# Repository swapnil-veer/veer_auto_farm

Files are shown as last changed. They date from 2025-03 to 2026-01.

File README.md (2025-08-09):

# veer_auto_farm
# Raspberry Pi-Based Auto Farm System

## Overview

This project is a **GSM/GPRS-controlled auto farm system** built using a **Raspberry Pi Zero 2 W**. The system automates motor control and monitors bypass mode, dry-run conditions, and phase availability using relays and sensors. It also includes an LCD display for real-time status updates.

## Hardware Components

- **Raspberry Pi Zero 2 W** – Main microcontroller
- **SIM800L** – GSM/GPRS module for remote control
- **ZMCT103C + ADS1115** – AC current sensor for dry-run detection
- **DPST Switch** – For detecting bypass mode
- **SRD-05VDC-SL-C Relays (2x)** – For motor on/off control and dry-run protection
- **Phase Monitoring Module** – Detects phase loss and faults
- **LCD (I2C)** – Displays system status
- **Power Setup**:
  - AC-DC Adapter (12V, 3A)
  - Li-Ion Batteries (4x DMEGC INR18650-26E)
  - BMS (2S 20A)
  - DC-DC Step Down (XL4015 - 5V, 4.2V, 12V)

## Wiring Diagram

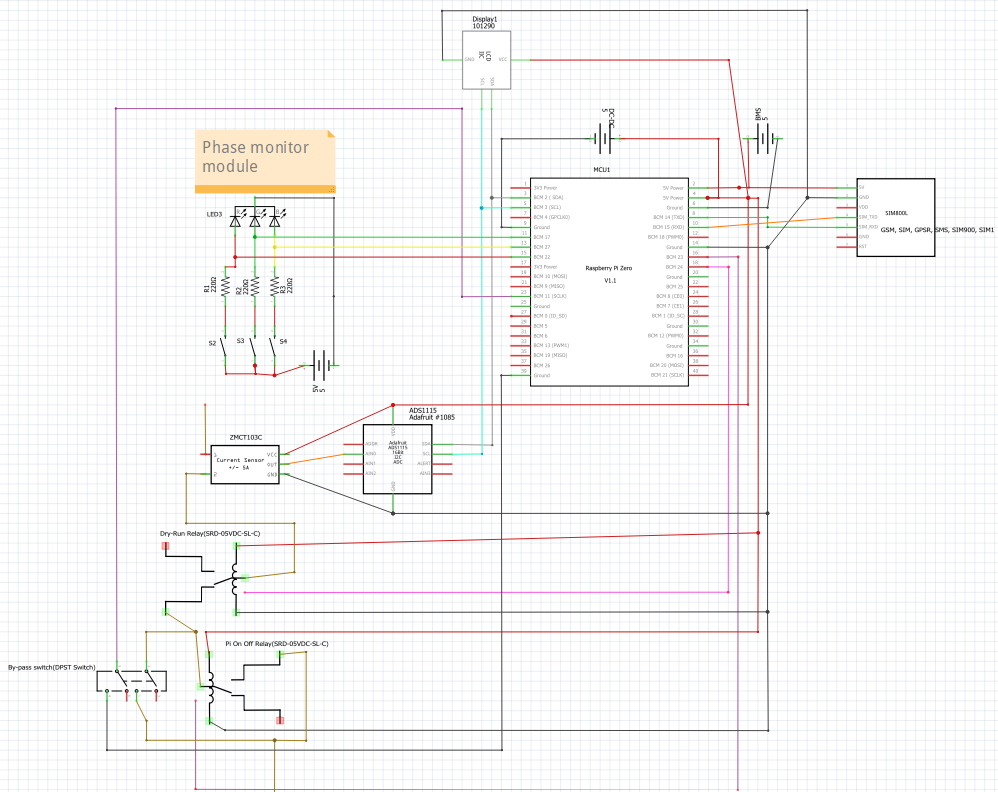
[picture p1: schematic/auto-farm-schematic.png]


### Key GPIO Connections:

| Component | GPIO Pin |
| --- | --- |
| **LCD (I2C)** | SDA (BCM 2), SCL (BCM 3) |
| **ZMCT103C + ADS1115** | I2C (SDA, SCL) |
| **Bypass Mode Detection (DPST Switch)** | GPIO 23 |
| **Dry-Run Relay** | GPIO 18 |
| **Pi On/Off Relay** | GPIO 16 |
| **Phase Monitor - Green (OK)** | GPIO 11 |
| **Phase Monitor - Yellow (Initial Wait)**  | GPIO 13 |
| **Phase Monitor - Red (Fault/Phase Loss)** | GPIO 15 |

## Setup Instructions

1. Clone the repository:
   ```sh
   git clone https://github.com/veer_auto_farm.git
   cd your-repo-name
   ```
2. Install dependencies:
   ```sh
   sudo apt update && sudo apt install python3-pip
   pip3 install RPi.GPIO smbus2 adafruit-circuitpython-ads1x15
   ```
3. Connect hardware as per the Fritzing schematic.
4. Run the main script:
   ```sh
   python3 main.py
   ```

## How It Works

- **Bypass Mode Detection**: A DPST switch changes state when the motor is manually turned on, and the Raspberry Pi detects it via GPIO 23.
- **Dry-Run Detection**: ZMCT103C AC current sensor (with ADS1115) checks if the motor draws current. If no current is detected, the motor is in dry-run mode.
- **Phase Monitoring**: The phase monitor module checks for faults and missing phases, updating GPIO states accordingly.
- **Motor Control**: The system controls relays connected to GPIO 16 (Pi On/Off Relay) and GPIO 18 (Dry-Run Relay) to automate motor operations.
- **LCD Display**: Displays real-time system status.

## Project Versioning Roadmap

We are following a phased development approach. Each version has multiple phases.  

### Version 0 — Core Power + Basic Motor Control
**Goal:** Safely power the system and achieve reliable motor ON/OFF control with manual override and logging.
#### Phase 1 — Power & Safety Setup
- [ ] Assemble power module (AC/DC adapter → buck converter → Pi 5V, motor 4V/relay)  
- [ ] Add smoothing capacitors, fuses, and protection diodes  
- [ ] Wire battery + BMS for backup power  
- [ ] Connect dry-run sensor wiring (not yet automated in code)  
- [ ] Test Pi boot stability on both adapter and battery  
**Acceptance Criteria:**  
- Pi runs for ≥2 hours on battery without reboot  
- Relays don’t chatter  
- Protection circuits functional  
#### Phase 2 — Motor Control by Pi
- [ ] Connect motor relay to Pi GPIO  
- [ ] Add manual ON/OFF switch in parallel  
- [ ] Python script to toggle motor ON/OFF  
- [ ] Log ON/OFF events to CSV  
- [ ] Manually test dry-run detection  
**Acceptance Criteria:**  
- Pi toggles motor reliably  
- Manual override works  
- Logs contain correct timestamps  

### Version 1 — Scheduling & local automation
- **Deliverables:** scheduling engine on Pi (cron or scheduler), simple UI or config file for schedules, logs retained.
- **Acceptance:** scheduled operations run and are logged; manual override still works.

### Version 2 — Remote I/O (ESP32) + wiring consolidation
- **Deliverables:** ESP32 at valve/filter location acting as remote I/O (relays for valves, solenoid, digital inputs), Pi sends commands over Wi-Fi; robust connector/cable layout.
- **Acceptance:** Pi can command valve open/close via ESP32 and get status back; local wiring reduced and tidy; fail-safe on comms loss.

### Version 3 — Filter automation (convert semi-auto → automated)
- **Deliverables:** solenoid flush + motor control integrated; limit switches or pressure-switch + comparator for fail-safe; ESP32 handles execution (local controller) but Pi schedules.
- **Acceptance:** automated flush cycle triggers on pressure threshold or on schedule; manual override available; no damage to filter in repeated cycles.

### Version 4 — Fertigation (pilot)
- **Deliverables:** fertigation pump/venturi control, recipe implementation (Pi), local execution via ESP32, safety interlocks (low-flow/pressure checks).
- **Acceptance:** a controlled trial run of fertigation with logs and rollback; confirmation of dosing accuracy.

### Version 5 — Full integration & pipeline changes
- **Deliverables:** finalize wiring, mechanical upgrades, central logs + backup, analytics pipeline (export to Google Sheets initially), documentation, maintenance checklist.
- **Acceptance:** system runs an end-to-end irrigation cycle with scheduled filter cleaning, valves working, and logged data; remote alerts enabled.

### Deployment Process
1. Develop & test in **Test Environment** (test hardware + test branch in Git).  
2. Review all functionality against acceptance criteria.  
3. Merge tested code into **Production Environment** (main branch + live hardware).  
4. Tag Git commit with version number (e.g., `v1.0-phase2`).  

## Future Improvements

- **Optimize power consumption**
- **Add logging and remote monitoring**
- **Enhance GSM module communication**

---

### Contributors

- **Swapnil Sanjay Veer** – Project Lead

### License

This project is licensed under the MIT License.

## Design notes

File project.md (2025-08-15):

For a structured Raspberry Pi project, follow this approach:

1. Project Structure

```

veer_auto_farm/  
│
├── README.md                          # Overview of the project
├── requirements.txt                   # Python dependencies
├── LICENSE                            # License file
│
├── IoT_Hub_Main_controller/           # Centralized IoT Hub Controller
│   ├── components_list.xlsx           # Components for IoT Hub
│   ├── circuit_diagrams/              # Diagrams for IoT Hub
│   ├── src/
│   │   ├── main.py                    # Main IoT Hub code
│   │   ├── config.py                  # All configurations (pins, thresholds)
│   │   ├── modules/                   # Modules used by IoT Hub
│   │   │   ├── gsm_module/
│   │   │   │   ├── gsm.py
│   │   │   │   ├── test_gsm.py
│   │   │   ├── lcd_display/
│   │   │   │   ├── lcd.py
│   │   │   │   ├── test_lcd.py
│   │   ├── utils/                     # Common helper functions
│   │   ├── tests/                     # IoT Hub level test scripts
│
├── RTUs/                              # All Remote Terminal Units
│   ├── pump_control_RTU/              # RTU for Pump control & sensing
│   │   ├── components_list.xlsx
│   │   ├── circuit_diagrams/
│   │   ├── src/
│   │   │   ├── pump_main.py
│   │   │   ├── config.py
│   │   │   ├── modules/               # If pump RTU has submodules
│   │   │   ├── utils/
│   │   │   ├── tests/
│   │
│   ├── Valve_control_RTU/             # RTU for irrigation sensors
│   │   ├── components_list.xlsx
│   │   ├── circuit_diagrams/
│   │   ├── src/
│   │   │   ├── irri_main.py
│   │   │   ├── config.py
│   │   │   ├── modules/
│   │   │   ├── utils/
│   │   │   ├── tests/
│   │
│   ├── filter_cleaner_RTU/            # RTU for filter automation
│   │   ├── ...
│
│   ├── ferti_RTU/                     # RTU for fertigation
│       ├── ...
│
└── global_tests/                      # System-level integration tests
    ├── end_to_end_test.py
  
```

2. Project Structure Explanation
### IoT_Hub (Central Controller)

- main.py → Runs the IoT Hub logic, manages communication with RTUs, and coordinates system behavior.

- config.py → Stores GPIO pins, LoRa/GSM settings, thresholds, and other constants.

- gsm_module/gsm.py → Handles GSM communication (SIM800L), sends SMS alerts, status updates, and remote commands.

- lcd_display/lcd.py → Updates the LCD with real-time system status and error messages.

- utils/ → Helper functions for logging, error handling, and common utilities used across modules.

- tests/ → Scripts for testing IoT Hub features (e.g., GSM connectivity, LCD rendering).

### RTUs (Remote Terminal Units)

Each RTU follows a similar modular structure, customized to its function.

- #### pump_control_RTU

- #### Valve_control_RTU

- #### filter_cleaner_RTU

- #### ferti_RTU

**end_to_end_test.py** → Simulates entire system operation, including IoT Hub + all RTUs communication, GSM alerts, LoRa tests, and fail-safe handling.

1. Python Virtual Environment (Optional but Recommended)
This ensures dependency isolation:

```
python3 -m venv venv
source venv/bin/activate
pip install -r requirements.txt
```
4. Running the Script
Once everything is set up, run:

```
python3 src/main.py 
```

This modular approach helps with debugging, reusability, and scalability.

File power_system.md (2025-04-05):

# Final Power System Components

## Overview
**Purpose:** Powers the Raspberry Pi (5V) and SIM800L (4V), with 8-10 hour battery backup, switching between 12V mains and 7.4V battery using a 12V relay.

## Component List

### Mains Adapter: 12V 2A AC-DC Adapter
- **Specs:** 230V AC to 12V DC, 2A (24W).
- **Purpose:** Primary power source, charges battery, energizes relay.
- **Source:** Amazon India (₹200-400), Flipkart, or local electrical stores.
- **Cost:** ₹200-400.

### Battery: 4x 18650 Li-ion Cells (2600mAh each, 2S2P configuration)
- **Specs:** 5.2Ah at 7.4V nominal (8.4V full, 6V discharged) = 38.48 Wh (16 hours at 2W).
- **Purpose:** Backup power for 8-10+ hours.
- **Source:** Amazon India (₹200-300 each), Robu.in, or local battery shops.
- **Cost:** ₹800-1200.
- **Note:** Use a battery holder or solder with care; ensure reputable cells (e.g., Samsung, Panasonic knockoffs).

### Battery Management System (BMS): 2S BMS (7.4V, 10A)
- **Specs:** Balances and protects 2S Li-ion pack, 10A max discharge.
- **Purpose:** Manages battery charging/discharging.
- **Source:** Amazon India (₹150-250), Robu.in, or local electronics markets.
- **Cost:** ₹150-250.

### Charger: TP5100 (2S Li-ion Charger Module, 1A)
- **Specs:** Input 5-15V (12V from adapter), output 7.4V at 1A to charge 2S battery.
- **Purpose:** Charges battery from 12V adapter.
- **Source:** Amazon India (₹100-200), Robu.in, or local shops.
- **Cost:** ₹100-200.

### Relay: 12V SPDT Relay (10A contacts)
- **Specs:** Coil voltage 12V (~40-70mA), switches 10A at 5V (NO/NC contacts).
- **Purpose:** Switches load between 12V adapter (NO) and 7.4V battery (NC).
- **Source:** Amazon India (₹50-100, search “12V SPDT relay”), Robu.in, or local vendors.
- **Cost:** ₹50-100.

### Buck Converters: 2x LM2596 (Adjustable, 3A)
- **Specs:** Input 4-40V, output adjustable (set to 5V and 4V), 3A max.
- **Purpose:**
  - LM2596 #1: 12V (adapter) or 7.4V (battery) → 5V for Pi (and LCD, relays, INA219).
  - LM2596 #2: 12V (adapter) or 7.4V (battery) → 4V for SIM800L.
- **Source:** Amazon India (₹100-150 each), Flipkart, or local electronics shops.
- **Cost:** ₹200-300 total.

### Capacitor: 1000µF (16V)
- **Specs:** Electrolytic capacitor, 16V rating.
- **Purpose:** Stabilizes SIM800L power during 2A transmission peaks.
- **Source:** Amazon India (₹20-50), local shops (common component).
- **Cost:** ₹20-50.

## Total Cost for Power System
- **Range:** ₹1520-2500 (~$18-30 USD).
- **Breakdown:**
  - Adapter: ₹200-400.
  - Battery: ₹800-1200.
  - BMS: ₹150-250.
  - Charger: ₹100-200.
  - Relay: ₹50-100.
  - Buck Converters: ₹200-300.
  - Capacitor: ₹20-50.

## Final Wiring Diagram (Locked)
```

[230V AC] → [12V 2A Adapter (+)] → [Relay NO] --+
                          |                     |
                          → [Relay Coil (+)]   |
                          |                     |
                          → [TP5100 (+)] → [2S BMS] → [Battery (7.4V)] → [Relay NC] --+
[Adapter (-)] → [TP5100 (-)]   [BMS (-)]       [Relay Coil (-)]                        |
                          |                     |                                       |
                          +---------------------+---------------------+                 |
                          |                     |                     |                 |
                          → [Load (-)] ← [Load (+)] ← [Relay COM] ←--+                 |
                                       |                                               |
                                       → [LM2596 #1 (5V)] → [RPi → LCD, Relays, INA219]
                                       → [LM2596 #2 (4V)] → [SIM800L + 1000µF]

```
## Schematic Wiring Diagram:
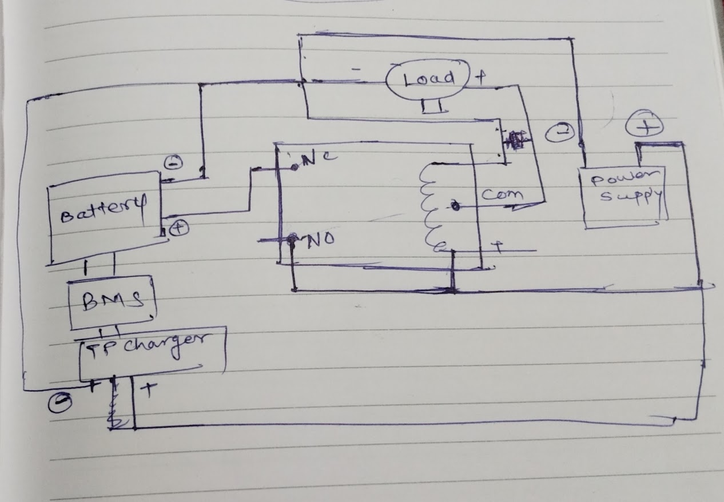
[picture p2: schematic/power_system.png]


## Confirmation
This is the locked-down power system:
- **Power Sources:** 12V 2A adapter (mains), 7.4V 2S2P battery (backup).
- **Switching:** 12V SPDT relay.
- **Outputs:** 5V (Pi and components), 4V (SIM800L).
- **Charging:** TP5100 with 2S BMS.
- **Components:** 7 items, total ₹1520-2500.

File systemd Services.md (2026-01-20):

# 🚀 Managing systemd Services (Raspberry Pi / Linux)

This document explains **how to create, enable, disable, debug, and remove a systemd service** for running a Python project automatically on boot.
Useful for **IoT, Raspberry Pi, server-side, and production-grade applications**.

---

## 📌 What is a systemd service?

A **systemd service** is a background process managed by Linux that:

* Can start automatically on boot
* Can be manually started/stopped
* Can restart automatically on failure
* Is widely used in production systems

---

## 📂 Service File Location

Custom services are stored at:

```bash
/etc/systemd/system/
```

Example:

```bash
veer-auto-farm.service
```

---

## 🚀 How to CREATE a systemd Service

### 1️⃣ Create the service file

```bash
sudo nano /etc/systemd/system/veer-auto-farm.service
```

### Paste the following content:

```ini
[Unit]
Description=Veer Auto Farm Controller
After=network.target

[Service]
User=pizero
WorkingDirectory=/home/pizero/projects/veer_auto_farm/IoT_Hub_Main_controller/src
ExecStart=/home/pizero/projects/veer_auto_farm/venv1/bin/python main.py
Restart=always
RestartSec=5

[Install]
WantedBy=multi-user.target
```

Save and exit:

* `CTRL + O` → Enter
* `CTRL + X`

---

### 2️⃣ Reload systemd (MANDATORY)

```bash
sudo systemctl daemon-reload
```

---

### 3️⃣ Enable service (auto-run on boot)

```bash
sudo systemctl enable veer-auto-farm.service
```

---

### 4️⃣ Start service immediately

```bash
sudo systemctl start veer-auto-farm.service
```

---

## ⛔ How to DISABLE Auto-Run

### Stop service now

```bash
sudo systemctl stop veer-auto-farm.service
```

### Disable service from starting on boot

```bash
sudo systemctl disable veer-auto-farm.service
```

---

## 🧪 How to CHECK Status & Debug
### Check list of services running

```bash
ls /etc/systemd/system/
```
### Check service status

```bash
sudo systemctl status veer-auto-farm.service
```

---

### View logs

```bash
journalctl -u veer-auto-farm.service
```

---

### View live logs (real-time)

```bash
journalctl -u veer-auto-farm.service -f
```

---

## 🗑️ How to REMOVE Service Completely

```bash
sudo rm /etc/systemd/system/veer-auto-farm.service
sudo systemctl daemon-reload
```

---

## ✅ Best Practices

* Use **systemd** instead of `cron` or `.bashrc`
* Always use **full paths** in `ExecStart`
* Use **virtual environment python**
* Keep service **disabled during development**
* Enable only in **production / deployment mode**

---

## 🎯 Interview-Ready Summary

> “I use systemd services to manage long-running applications.
> I define a service file under `/etc/systemd/system/`, specify execution details, and control auto-start using `systemctl enable` or `disable`.
> This approach provides reliability, restart handling, and production-level control.”

---

📌 **End of Document**

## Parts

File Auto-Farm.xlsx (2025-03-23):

Auto -Farm Module
Component | Model | Qty
Relay | SRD-05VDC-SL-C | 2
DPST Button |  | 1 | for bypass mode We can use DPST even if motor is off
Dry- run | ZMCT103C + ADS1115 | 1

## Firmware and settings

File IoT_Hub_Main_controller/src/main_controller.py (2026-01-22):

import re
from settings import DEFAULT_DURATION

class MainController:
    """
    Central brain:
    - Receives user intents (SMS, HTTP, etc.)
    - Delegates to CommandProcessor for pump control
    - Builds response messages for users
    - Reads system status (phase_monitor, CommandProcessor state)
    """

    def __init__(self, command_processor, led_monitor, sms_thread, logger):
        self.command_processor = command_processor    # CommandProcessor instance
        self.led_monitor = led_monitor
        # self.phase_data = phase_data                  # global dict from phase_monitor
        self.sms = sms_thread
        self.logger = logger
        self._event_handler = EventHandler(sms=self.sms, logger=self.logger)
        self.power_service = PowerStatusService(led_monitor)

    # === PUBLIC ENTRY POINT (for SMS layer) ===
    def handle_incoming_sms(self, sender: str, text: str) -> str:
        """
        Entry point called by sms_processor.
        Parses the SMS text at a high level, decides action,
        and returns a reply string to send back to this sender.
        """
        # delete_one_command
        if re.search(r'\b(OFF|STOP|SHUT\s*DOWN)\b', text, flags=re.IGNORECASE):
            cmd = self._create_command('DELETE_ONE', sender)
            self.command_processor.handle(cmd)
            return "Pump OFF request received."

        # delete_all_commands   
        elif re.search(r'\b(ALL OFF)', text, flags=re.IGNORECASE):
            cmd = self._create_command('DELETE_ALL', sender)
            self.command_processor.handle(cmd)
            return "All commands cleared."

        # STATUS
        elif re.search(r'\bSTATUS\b', text, flags=re.IGNORECASE):
            return self._handle_status(sender=sender)
        
        # For auto mode
        elif re.search(r'\b(Auto|Auto on)\b', text, flags=re.IGNORECASE):
            # TODO: replace direct add_command call with brain.handle_incoming_sms
            cmd = self._create_command('AUTO_ON', sender)
            self.command_processor.handle(cmd)
            return "Request accepted: Pump ON in AUTO mode."
        
        # ON with optional duration
        elif re.search(r'\b(ON|START)\b', text, flags=re.IGNORECASE):
            m = re.search(r'(\d+)', text)
            if m:
                min = int(m.group(1))
            else:
                min = DEFAULT_DURATION
            cmd = self._create_command('MANUAL_ON', sender, min)
            try :
                self.command_processor.handle(cmd)
            except ValueError as err_msg:
                return err_msg
            return f"Request accepted: Pump ON for {min} min."

        else:
            return self._handle_invalid(sender=sender)
        
    def _create_command(self, ctype: str, sender: str, duration_minutes: int = None) -> dict:
        """Factory: SMS intent → standard command_dict
            Creating commands for command processor     """
        priority_map = {
            'MANUAL_ON': 1,
            'AUTO_ON': 2,
            'DELETE_ONE': 3,
            'DELETE_ALL': 4
        }
        
        cmd = {
            'ctype': ctype,
            'priority': priority_map[ctype],
            'sender': sender,
            'status': 'created',
            'terminated_by': None  
        }
        
        if duration_minutes:
            cmd['duration_sec'] = duration_minutes * 60
            cmd['remaining_sec'] = duration_minutes * 60
        
        # TODO: db_cmd = Command(ctype=ctype, sender_phone=sender, status='created')
        # TODO: db.session.add(db_cmd); db.session.commit()
        # TODO: cmd['db_id'] = db_cmd.id
        return cmd
        
    def get_system_status(self) -> dict:
        """
        Central status provider.
        Uses phase_data, command_processor, sms_thread, etc.
        Returns a single, stable structure for all UIs.
        """
        cmd = self.command_processor.current_command
        mode = cmd["mode"] if cmd else None

        if mode == "manual":
            manual_remaining_min = round(cmd["remaining_sec"] / 60)
        else:
            manual_remaining_min = None

        status = {
            "power": self.power_service.is_power_available(),
            "mode": mode,                                                    # 'manual' / 'auto' / None
            "pump_on": self.command_processor.pump_context_manager.relay_manager.get_pump_state(),  # from pump_manager
            "manual_remaining_min": manual_remaining_min,  # None in auto/idle
            "sim_ok": self.sms.get_sim_status(),
            "signal_strength": self.sms.get_signal_strength() or 0,
        }
        return status
        
    # === COMMAND HANDLERS (internal to MainController) ===

    def _handle_off(self, sender: str) -> str:
        """
        Handle OFF / STOP request:
        - tell CommandProcessor to delete current command
        - build acknowledgement message
        """
        self.command_processor.delete_one()
        return "Pump OFF request received. Stopping current command (if any)."

    def _handle_all_off(self, sender: str) -> str:
        """
        Handle ALL OFF request:
        - delete current + queued commands
        """
        self.command_processor.delete_all()
        return "All commands cleared. Pump will be OFF."

    def _handle_manual_on(self, sender: str, minutes: int) -> str:
        """
        Handle 'ON <minutes>' or default ON.
        """
        self.command_processor.add_command(duration_minutes=minutes, sender=sender)
        return f"Request accepted: Pump ON for {minutes} min."

    def _handle_auto_on(self, sender: str) -> str:
        """
        Handle AUTO mode start.
        """
        self.command_processor.add_command(sender=sender, mode="auto")
        return "Request accepted: Pump ON in AUTO mode (runs until OFF)."

    def _handle_status(self, sender: str) -> str:
        """
        Build status message using phase_data + CommandProcessor state + LCD helper.
        """
        status = self.get_system_status()
        power = status["power"]
        pump_text = "ON" if status["pump_on"] else "OFF"
        rem = status["manual_remaining_min"]
        rem_part = f"REM:{rem} min" if rem is not None else ""
        
        if status["mode"] == "auto":
            if status["pump_on"]:
                return f"PWR:{power}, PUMP:{pump_text} AUTO"
            else:
                return f"PWR:{power}, PUMP:{pump_text} AUTO WAIT PWR"
        return f"PWR:{power}, PUMP:{pump_text}{rem_part}"

    def _handle_invalid(self, sender: str) -> str:
        """
        For unrecognized commands, return help text.
        """
        sample_msg = """
            Please send msg in correct format.
            Accepts messages like:
            - 'PUMP ON 120', 'ON 120', 'START 120'
            - 'PUMP ON' (uses default)
            - 'AUTO ON' - Motor starts in Auto mode
            - 'OFF', 'STOP' - Off Auto mode / Delete Current Commands.
            - 'ALL OFF' - Delete all commands.
            - 'STATUS'
            """
        return sample_msg
    
    # Events
    def handle_event(self, event: dict) -> None:
        """Entry point for CommandProcessor events."""
        self._event_handler.handle(event)


class EventHandler:
    """Only event-specific logic; no orchestration."""
    def __init__(self, sms, logger):
        self.sms = sms
        self.logger = logger

    def handle(self, event: dict) -> None:
        etype = event.get("type")
        data = event.get("data", {})

        dispatch = {
            "PUMP_STARTED": self._pump_started,
            "PUMP_COMPLETED": self._pump_completed,
            "PUMP_ABORTED_POWER_LOSS": self._on_power_loss,
            "PUMP_AUTO_STOPPED": self._on_pump_auto_stopped,
            "PUMP_ABORTED_MANUAL_STOP": self._on_pump_man_stopped,
            "COMMAND_DELETED_CURRENT": self._on_command_deleted,
        }
        handler = dispatch.get(etype)
        if handler:
            handler(data)
        else:
            self.logger.warning(f"Unknown event: {etype} {data}")

    def _pump_started(self, data: dict) -> None:
        sender = data.get("sender")
        mode = data.get("mode")
        duration_min = data.get("duration_min")
        if sender:
            if mode == "manual" and duration_min:
                text = f"Pump started for {duration_min} min."
            else:
                text = "Pump started in AUTO mode."
            self.sms.send_sms(sender, text)
        self.logger.info(f"PUMP_STARTED: {data}")
    
    def _pump_completed(self, data: dict) -> None:
        sender = data.get("sender")
        mode = data.get("mode")
        duration_min = data.get("duration_min")
        if sender:
            text = f"Pump completed. {duration_min} min total"
            self.sms.send_sms(sender, text)
        self.logger.info(f"PUMP_COMPLETED: {data}")
    
    def _on_power_loss(self, data : dict) -> None:
        sender = data.get("sender")
        mode = data.get("mode")
        duration_min = data.get("duration_min")
        if sender:
            if mode == "manual" and duration_min:
                text = f"Power loss. Waiting, {duration_min} min left"
            else:
                text = "Power loss in AUTO mode. Waiting for power to resume."
            self.sms.send_sms(sender, text)
        self.logger.info(f"PUMP_ABORTED_POWER_LOSS: {data}")

    def _on_pump_auto_stopped(self, data : dict) -> None:
        sender = data.get("sender")
        if sender:
                text = f"AUTO mode stopped by user {sender}"
                self.sms.send_sms(sender, text)
        self.logger.info(f"PUMP_AUTO_STOPPED: {data}")

    def _on_pump_man_stopped(self, data : dict) -> None:
        sender = data.get("sender")
        if sender:
                text = f"Pump manually stopped by user {sender}"
                self.sms.send_sms(sender, text)
        self.logger.info(f"PUMP_ABORTED_MANUAL_STOP: {data}")

    def _on_command_deleted(self, data: dict) -> None:
        sender = data.get("sender")
        if sender:
                text = f"This Command deleted without run by user {sender}"
                self.sms.send_sms(sender, text)
        self.logger.info(f"COMMAND_DELETED_CURRENT: {data}")

class PowerStatusService:
    def __init__(self, led_monitor):
        self.led_monitor = led_monitor
    
    def is_power_available(self) -> bool:
        return self.led_monitor.is_power_available()
    
    def get_status(self) -> str:
        return self.led_monitor.get_status()

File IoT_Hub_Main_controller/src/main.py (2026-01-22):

import config
config.cleanup_gpio()
config.setup_gpio()

from main_controller import MainController

import threading
from settings import SENSORS
from file_manager import log_sensors
from modules.phase_monitor import LedMonitor, phase_data
from modules.lcd_display.lcd_module import LCD
import time
from logging_config import logger
from modules.pump_control import PumpManager, PumpContextManager
from command_processor import CommandProcessor
from modules.sim800l.sim import sms_thread
from modules.sim800l.sms_processor import sms_processor, set_controller

#create pump manager instance
pump_manager = PumpManager()
pump_context_manager = PumpContextManager(pump_manager)
led_monitor = LedMonitor(poll_interval=1)

# command_processor instance
processor = CommandProcessor(
    pump_context_manager=pump_context_manager,
    logger=logger,
    poll_interval=5,
)

# Create MainController (central brain)
main_controller = MainController(
    command_processor=processor,
    led_monitor = led_monitor,
    sms_thread=sms_thread,
    logger=logger,
)

# Wire CommandProcessor -> MainController for events (आधी event_handler field add केलेला असेल तर)
processor.event_handler = main_controller.handle_event
processor.power_service = main_controller.power_service

# Wire SMS side -> MainController for incoming commands
set_controller(main_controller)
time.sleep(2)

lcd = LCD(main_controller=main_controller, logger=logger)          # Lcd thread started
time.sleep(2)

thread = threading.Thread(target=sms_processor, daemon=True)
thread.start()  


time.sleep(5)
log_sensors(sensors=SENSORS)
time.sleep(5)

t2 = threading.Thread(target=processor.run, daemon=True)
t2.start()

try:
    while True:
        time.sleep(2)
except KeyboardInterrupt:
    config.cleanup_gpio()
    logger.info("Main loop interrupted - cleanup already registered")

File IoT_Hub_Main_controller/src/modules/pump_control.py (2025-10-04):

import time
from contextlib import contextmanager
from config import GPIO_PINS, set_high, set_low



class PumpContextManager:
    """
    Context manager for safely turning the relay on and off.
    Ensures relay is turned off on exit, even if exceptions occur.
    """
    def __init__(self, relay_manager):
        self.relay_manager = relay_manager
        self.is_on = False

    def __enter__(self):
        self.relay_manager.relay_on()
        self.is_on = True
        return self

    def __exit__(self, exc_type, exc_val, exc_tb):
        if self.is_on:
            self.relay_manager.relay_off()
        # Re-raise exception if any
        return False

class PumpManager:
    """
    Core relay manager for relay control and power state.
    """
    def __init__(self):
        self.power = False
        self.state = False         #Default off
        self.pump_pin = GPIO_PINS["relay_pi_onoff"]["pin"]

    def relay_on(self):
        """Turn relay on."""
        print("Relay turned ON")
        self.state = True
        set_high(self.pump_pin)

    def relay_off(self):
        """Turn relay off."""
        print("Relay turned OFF")
        self.state = False
        set_low(self.pump_pin)

    def set_power(self, state: bool):
        """Set power state."""
        self.power = state

    def get_pump_state(self):
        return self.state

pump_manager = PumpManager()
pump_context_manager = PumpContextManager(pump_manager)

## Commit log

2025-03-30 sim800l.py replaced by comm.py
    [comm.py, config.py]
2025-04-05 motor control added
2025-04-05 power system added
2025-05-21 schematic added
2025-08-17 clear all files for production branch
    [Auto-Farm.xlsx, Auto-farm.fzz, Virtual_motor_auto_switch.fzz]
2025-08-24 Revert "Main"
    [Auto-Farm.xlsx, Auto-farm.fzz, Virtual_motor_auto_switch.fzz]
2025-08-25 added logic for phase_monitor and motor control
2025-08-25 moved motor_control and phase_monitor inside modules
2025-08-27 main and motor control modified
2025-09-16 trying new logic for pump
2025-09-17 minor error fix at testing
    [command_processor.py, config.py, main.py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]
2025-09-20 added led monitering unit
2025-09-24 motor_control, sim800l, sms_processor removed
2025-12-17 main.py wiring
2025-12-27 restructured for led moniter
